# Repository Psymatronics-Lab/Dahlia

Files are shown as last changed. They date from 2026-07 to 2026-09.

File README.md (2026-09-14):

<p align="center">
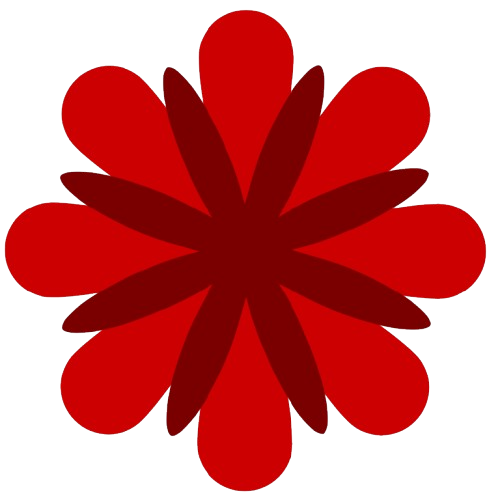
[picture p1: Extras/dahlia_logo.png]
Dahlia Logo
  
</p>

# Dahlia
**Dahlia** is a open-source, 5+1 DOF robotic arm designed for small scale pick and place, educational, and data collection tasks.
<p align="center">
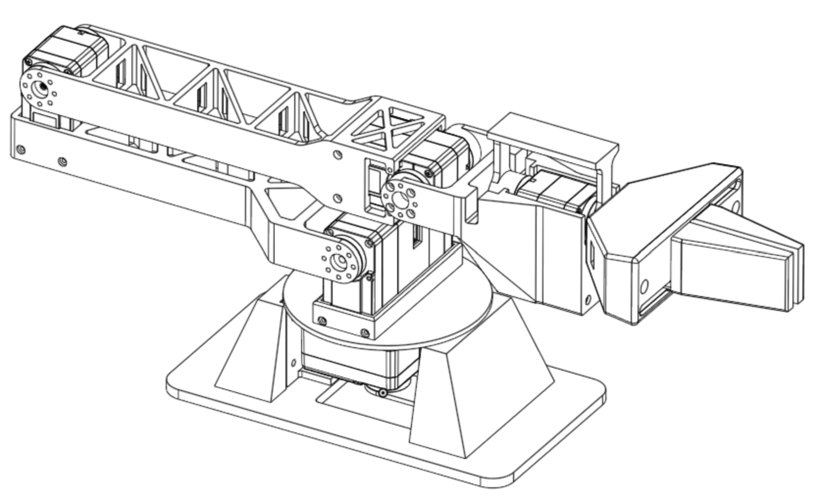
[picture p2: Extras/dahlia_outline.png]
Dahlia Outline
  
</p>

The primary inspiration for the design was the [LeRobot and Huggingface SO-101](https://huggingface.co/docs/lerobot/en/so101) open-source robotic arm, and the [HiWonder NexArm](https://www.hiwonder.com/products/nexarm). The goal of the project was to design an open-source arm with 3D-printable hardware, at a fairly accessible price, while improving upon the specifications of the SO-101 and similar arms in terms of load capacity, reach, and form factor.

This repository contains the hardware, firmware, and software for the Dahlia arm and its SEC controller, organized as follows:
```text
Dahlia/
├── Hardware/
│   ├── dahlia_hardware/          # Arm printed parts (base, arm, end effector), URDF, and sim scripts
│   └── sec_hardware/             # SEC controller printed parts, components, and wiring
├── Firmware/
│   ├── dahlia_firmware/          # Arduino App Lab app for the UNO Q
│   │   ├── sketch/               # MCU servo loop and SPI service
│   │   ├── bricks/spi_service/   # MPU-side HTTP to SPI bridge
│   │   └── python/               # Kinematics and SEC teleoperation control
│   ├── dahlia_services/
│   │   ├── HXServo/              # Arduino library for Hiwonder HX bus servos
│   │   └── controller_service/   # BLE proxy service for the SEC on the UNO Q
│   └── sec_firmware/             # ESP32-S3 firmware for the SEC controller
├── Software/
│   ├── lerobot/                  # LeRobot plugin for the arm and SEC teleoperator
│   └── perception/               # Prototype MicroTag detection pipeline
└── Extras/
    ├── microtag_block/           # Printable MicroTag fiducial blocks
    └── utilities/                # Servo ID hotfix and servo visualization tools
```

## Design, Stack, and BOM
The full CAD design for the Dahlia arm were created using OnShape and a bit of Autodesk Fusion. All editable CAD files are available on the [OnShape Document](https://cad.onshape.com/documents/8e567048457d8f314f3cf9ea/w/dc4364e539049e2561969525/e/322bc6f20473a79fe384e2b4). 

Dahlia is a 5+1 DOF arm, consisting of base rotation joint, co-planar shoulder, elbow, and wrist-pitch joints, and a wrist-roll joint, as well as a gear-driven linear clamp as the end effector. HiWonder bus servos were chosen to be the main actuators for the design due to their relatively low cost for power trade off and similar firmware interface as Feetech STS servos. A Arduino UNO Q is used to directly interface with the BusLinker servo controller to control the arm. A webcam can be mounted on-top of the arm, attached to the wrist-roll bracket, for vision and data collection. Wiring channels and lightening holes are built into the design to reduce material usage and improve wire management.

A full bill of materials needed to construct the arm is listed below. *Note that some manufacturing and connective equipment, such as a 3D printer (BambuLab X2D was used for all prints in construction), hex keys, soldering iron and USB-C cabling are not included.*
| **Component** | **Link** | **Units** | **Price (at time)** | **Total Price** |
| --- | --- | ---: | ---: | ---: |
| Hiwonder HX-30HM | [Hiwonder](https://www.hiwonder.com/products/hx-30hm?variant=42135141253207) | 4 | $19.99 | $79.96 |
| Hiwonder HX-65HM | [Hiwonder](https://www.hiwonder.com/products/hx-65hm?variant=42066913132631) | 1 | $49.99 | $49.99 |
| Hiwonder BusLinker v3 | [Hiwonder](https://www.hiwonder.com/products/buslinker) | 1 | $9.99 | $9.99 |
| Hiwonder LFD-01M | [Hiwonder](https://www.hiwonder.com/products/lfd-01m?variant=39328236896343) | 1 | $6.99 | $6.99 |
| Arduino UNO Q 4GB | [Arduino](https://store-usa.arduino.cc/pages/uno-q) | 1 | $59.99 | $59.99 |
| M3 Heat Set Inserts | [Amazon](https://www.amazon.com/Threaded-Inserts-Plastic-3mm-10mm-Pringting/dp/B0FD88XTV4/) | 1 | $9.99 | $9.99 |
| M3 Screws | [Amazon](https://www.amazon.com/Fgruh-750PCS-Assortment-Washers-Assorted/dp/B0FGV5FCBN/) | 1 | $9.99 | $9.99 |
| M2 Screws | [Amazon](https://www.amazon.com/Fgruh-1260pcs-M2-Assortment-Stainless/dp/B0FG2CC91J/) | 1 | $9.99 | $9.99 |
| Logitech C270 Webcam | [Amazon](https://www.amazon.com/Logitech-Desktop-Widescreen-Calling-Recording/dp/B004FHO5Y6) | 1 | $16.89 | $16.89 |
| 9V Barrel Jack Power Supply | [Amazon](https://www.amazon.com/Interchangeable-Switching-Compatible-Universal-Electronics/dp/B0CPPPKP91/) | 1 | $9.99 | $9.99 |
| | | | **Total Cost:** | **$263.77** |
> [!NOTE]
> A [HiWonder bus servo controller](https://www.hiwonder.com/products/serial-bus-servo-controller) instead of a BusLinker and Arduino UNO Q setup, to directly command the arm from a local computer, may be more cost-efficient and effective for some applications.

## Assembly and Setup
To assemble the arm, acquire the components listed in the BOM, and print the 3D-printable components in the hardware `.step` files for each section of the arm, using any 3D printer (around 0.5kg of PLA filament should be sufficient).

Use the following instructions to construct the arm.
1. Attach all included servo horns to the HiWonder servos, and set each servo to a different ID using the BusLinker board.
2. Use a soldering iron to set the 4 heat-set inserts into the holes in the base plate.
3. Use M2 screws to attach a HX-30HM servo (**base rotation**) to the base servo mount, and attach the base rotation bracket to the servo horns using M2 screws.
4. Attach the base servo mount to the base plate using M3 screws, ensuring the servo wire ports are oriented upward. Attach two wires into the servo ports, and route one wire through the wire divot in the base plate.
5. Attach the rotation plate to the base rotation servo and base rotation bracket using M2 screws.
6. Mount the HX-65HM servo (**shoulder**) into the rotation plate, using its included screws to mount it to the plate, and connect the base rotation servo wire not routed through the divot to the shoulder servo.
7. Mount a HX-30HM servo (**elbow**) into the upper arm using M2 screws, then attach the upper arm to the shoulder servo using M2 screws.
8. Mount a HX-30HM servo (**wrist pitch**) into the lower arm using M2 screws, then attach the lower arm to the elbow servo using M2 screws.
9. Mount the wrist roll bracket on the remaining HX-30HM servo (**wrist roll**) using M2 screws, then mount the wrist roll servo into the wrist using M2 screws.
10. Attach the wrist to the wrist pitch servo, using M2 screws.
11. Mount the end effector housing onto the wrist roll servo and wrist roll bracket using M2 screws.
12. Mount the LFD-01 servo (**end effector**) into the end effector housing using M2 screws, and attach the end effector gear directly to the servo using the servo's horn screw.
13. Slot the linear clamps through the end effector cap and into the housing channels symmetrically on either side of the gear, then attach the cap to the housing using M3 screws.
14. Connect the bus servos together with wiring, threaded through the wiring channels in the upper and lower arms, and connect the end effector servo to the Arduino UNO Q.
15. Connect the other bus wire on the base rotation servo to the BusLinker, and connect the TX/RX channels of the BusLinker to the Arduino UNO Q, ensuring that the bridges on the BusLinker are between Servo and TTL, and not Servo and USB.

All firmware and software needed to run and command the arm is provided in the repository. Refer to the `README.md` and related documentation in the `Software/` and `Firmware/` folders to conduct this setup, which involves creating an AppLab app, setting up services on the Arduino UNO Q, installing the app, and using an external Bluetooth controller to send commands to the UNO Q.

The repository additionally includes a full HXServo library, for control of HiWonder servos, adapted from HiWonder firmware code.
- BusLinker Documentation [https://docs.hiwonder.com/projects/BusLinker/en/latest/index.html](https://docs.hiwonder.com/projects/BusLinker/en/latest/index.html)
- Public Firmware for HX-30HM [https://drive.google.com/drive/folders/1ZyeM3iiXFUqOsPx-hs1AgcEjACiQLcII](https://drive.google.com/drive/folders/1ZyeM3iiXFUqOsPx-hs1AgcEjACiQLcII)

> [!IMPORTANT]
> Due to resourcing constraints in constructing a leader-follower arm setup, Dahlia is originally designed to work with a SEC (Semi-Extensible Controller), for which there is provided firmware and hardware designs in this repository. However, because the Bluetooth Low Energy service is implementation-agnostic and instead uses a standardized packet format, it is possible to use another Bluetooth-compatible controller to control the arm.

## Usage
Once the arm is assembled and the firmware is set up, the arm can be driven directly with the SEC, recorded and replayed through LeRobot, or commanded by any program that reaches the UNO Q over HTTP.

```text
  SEC controller ──BLE──► controller_service (:8000) ──► python/main.py ──► spi_service (:9000) ──SPI──► MCU ──► servos
                                                                                 ▲
                                                           LeRobot, servo_viz, or custom programs over HTTP
```

### Controlling the Arm with the SEC
1. Make sure the `sec-controller` service is running on the UNO Q (see [`controller_service`](Firmware/dahlia_services/controller_service/README.md)).
2. Power the arm and start the Dahlia Firmware app in App Lab. On startup, the MCU drives every joint to its zero pose, so keep the workspace clear.
3. Power the SEC, holding it still with the joystick centered while it calibrates. The arm begins responding once the controller connects.

| **Input** | **Effect** |
| --- | --- |
| Joystick X | Moves the end effector straight up and down |
| Joystick Y | Moves the end effector toward or away from the base |
| Joystick button (**hold**)  | Gyroscopic following: controller roll turns the base, controller pitch tilts the end effector |
| Rotary encoder (**turn**) | Rolls the end effector |
| Encoder button (**click**)  | Toggles the clamp fully open or fully closed |
| **Both buttons** | Returns the arm to its startup pose |

The LED matrix on the SEC shows the joystick, button, and IMU readings for quick diagnostics. Motion speeds, joystick thresholds, and safety limits can be tuned in [`control.py`](Firmware/dahlia_firmware/python/control/control.py), and are explained in the [control README](Firmware/dahlia_firmware/python/README.md).

### Using LeRobot
The [`lerobot-dahlia`](Software/lerobot/README.md) plugin runs on a separate PC and provides the arm as the `dahlia` robot and the SEC as the `dahlia_sec` teleoperator, both reached at the UNO Q's SPI service URL.

```bash
pip install -e "Software/lerobot[camera]"

# check the connection to the arm without LeRobot
python -m lerobot_dahlia.dahlia_bus http://dahlia.local:9000

# record episodes while driving the arm with the SEC
lerobot-record \
  --robot.type=dahlia --robot.port=http://dahlia.local:9000 \
  --teleop.type=dahlia_sec --teleop.port=http://dahlia.local:9000 \
  --robot.discover_packages_path=lerobot_dahlia \
  --dataset.repo_id=you/dahlia_pick --dataset.num_episodes=10 \
  --dataset.single_task="Pick up the block"
```

- **Teleoperating and recording.** The SEC control loop stays on the UNO Q, and LeRobot only reads what the arm is being commanded. The robot defaults to `read_only=true` for these tasks, so LeRobot never fights the SEC.
- **Replaying and running policies.** Pass `--robot.read_only=false` so LeRobot commands the arm, and disconnect the SEC first so only one program is driving it.
- **Cameras.** The wrist camera is recorded as `observation.images.wrist`. Find its device index with `lerobot-find-cameras opencv` and set it in `dahlia_robot.py` or with `--robot.cameras`.

### Developing with Dahlia
The SPI service on the UNO Q exposes the arm over HTTP on port `9000`, so new software can be written in any language on the board or on another machine on the network.

| **Endpoint** | **Use** |
| --- | --- |
| `GET /config` | Joint names, tick limits, and angle limits |
| `GET /feedback` | Measured joint angles in radians |
| `POST /targets` | Command joint angles in radians |
| `GET /motors` | Full raw motor state, including load, voltage, and temperature |
| `POST /motors` | Command raw servo ticks, or `{"hold": true}` to hold the current pose |
| `GET /command` | What the arm is currently being commanded, and in which mode |
| `GET /health` | SPI service status |

> [!WARNING]
> Only one program should command the arm at a time. `POST /targets` and `POST /motors` overwrite each other, so a second writer will cause the arm to jerk between commands. All commands are still clamped to the joint limits set in the MCU firmware.

A few starting points in the repository:
- **New control schemes.** [`kinematics.py`](Firmware/dahlia_firmware/python/control/kinematics.py) provides closed-form forward and inverse kinematics, and [`main.py`](Firmware/dahlia_firmware/python/main.py) is a short example of reading a controller and posting joint targets.
- **Other controllers.** Any BLE device that sends the SEC packet format in [`ble.h`](Firmware/sec_firmware/src/ble/ble.h) can replace the SEC, and the SEC's breadboard and firmware can be extended with new inputs.
- **Monitoring.** [`servo_viz`](Extras/utilities/servo_viz/README.md) plots commanded against measured joint angles live from a workstation, using only read-only endpoints.
- **Simulation.** The URDF in [`Hardware/dahlia_hardware`](Hardware/dahlia_hardware/README.md) can be converted to a simulation-ready model for simulation and RL training.
- **Perception.** [`Software/perception`](Software/perception/) contains an OpenCV detection pipeline for the [MicroTag blocks](Extras/microtag_block/README.md).

## Notes and Acknowledgements
Dahlia was designed in part for the "Invent the Future with Arduino UNO Q and App Lab" challenge, hosted by [Hackster.io](https://www.hackster.io/contests/invent-the-future-with-arduino-uno-q-and-app-lab). Thank you to Hackster.io for providing the Arduino UNO Q hardware that was used to design and construct the project.

> [!NOTE]
> As the first project for the Psymatronics Lab, there is definitely more extension to be done on Dahlia and much was learned from designing and troubleshooting the arm. I hope to continue to build out the software stack of Dahlia, and begin designing **Dahlia II**, which will be an enhanced arm, designed for low-cost research and data-collection applications.

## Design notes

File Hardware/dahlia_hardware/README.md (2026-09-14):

# Dahlia Arm Hardware
All the `.step` files needed to print a Dahlia arm are included in this section of the repository, alongside `.urdf` files and meshes for simulation and RL training.

The full URDF contains a few unnecessary joints and sections that may hamper simulation performance, and thus a simulation-ready version with merged meshes and proper joints can be generated using the following code. Only `numpy` needs to be installed for this.
```bash
python urdf_merge_subassemblies.py path/to/robot_full/urdf/robot_full.urdf -o path/to/robot_sim
```

## Printed Parts
| **Folder** | **Files** |
| --- | --- |
| `base/` | `base_body`, `base_servo_mount`, `base_rotation_plate`, `base_rotation_bracket` |
| `arm/` | `arm_upper_arm`, `arm_lower_arm`, `arm_wrist`, `arm_wrist_rotation` |
| `end_effector/` | `ef_body`, `ef_gear`, `ef_clamp` (print two, one per side), `ef_front_cap` |

## Components
| **Component** | **Units** | **Purpose** |
| --- | ---: | --- |
| Hiwonder HX-65HM | 1 | Shoulder joint |
| Hiwonder HX-30HM | 4 | Base rotation, elbow, wrist pitch, and wrist roll joints |
| Hiwonder LFD-01M | 1 | PWM servo driving the end effector gear and clamp |
| Hiwonder BusLinker v3 | 1 | Bridges the UNO Q's UART to the servos' single-wire serial bus |
| Arduino UNO Q | 1 | Runs the servo loop (MCU) and the control and BLE services (MPU) |
| 9V power supply | 1 | Servo power, through the BusLinker's DC input |
| Logitech C270 webcam  | 1 | Optional, mounted to the wrist-roll bracket for vision |

See the BOM in the [main README](../../README.md) for purchase links and fasteners.

## Wiring
```text
  9V supply ──► BusLinker v3 DC input
                     │
  UNO Q Serial1 ◄──► BusLinker v3 ──bus──► HX servos (IDs 1-5, daisy-chained)
  UNO Q D3 (PWM) ─────────────────────────► LFD-01M clamp servo
```

### Bus Servos
| **UNO Q** | **BusLinker v3** | **Notes** |
| --- | --- | --- |
| `Serial1` TX  | RX | TX and RX are crossed |
| `Serial1` RX  | TX | TX and RX are crossed |
| GND | GND | A shared ground is required |

The servos are daisy-chained from the BusLinker's servo bus and powered from the BusLinker's DC input, never from the UNO Q's 5V pin. The bus runs at 1,000,000 baud, and each servo must be assigned the ID the firmware expects, from [`servo_interface.h`](../../Firmware/dahlia_firmware/sketch/src/low_level/servo_interface.h):

| **Joint** | **Servo** | **ID** |
| --- | --- | -----: |
| Base rotation| HX-30HM | 1 |
| Shoulder | HX-65HM | 2 |
| Elbow | HX-30HM | 3 |
| Wrist pitch  | HX-30HM | 4 |
| Wrist roll | HX-30HM | 5 |

Set IDs with one servo connected at a time, since servos sharing an ID on the same bus will corrupt it. [`Extras/utilities/id_hotfix.ino`](../../Extras/utilities/id_hotfix.ino) can be used to change a servo's ID.

### Clamp Servo
The LFD-01M signal wire connects to UNO Q pin D3 (`SIGPIN` in `servo_interface.h`), which is driven with a 50 Hz PWM signal. Its ground must be shared with the UNO Q.

### UNO Q and Webcam
The UNO Q is powered over USB-C. The webcam connects over USB to the device used for vision and data collection (not necessarily the UNO Q). Route servo cables through the wiring channels built into the printed parts.

For further wiring and bus troubleshooting details, see the [HXServo README](../../Firmware/dahlia_services/HXServo/README.md).

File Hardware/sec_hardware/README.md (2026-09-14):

# Semi-Extensible Controller Hardware
The 3D-printable parts for the SEC (Semi-Extensible Controller) are in this section of the repository. The SEC is a handheld Bluetooth Low Energy controller used to teleoperate the Dahlia arm. Firmware and setup instructions are in [`Firmware/sec_firmware`](../../Firmware/sec_firmware/).

## Printed Parts
| **File** | **Description** |
| --- | --- |
| `sec_body.step` | Main controller body |
| `sec_encoder_knob.step`| Knob for the rotary encoder shaft |

## Components
| **Component** | **Model** | **Purpose** |
| --- | --- | --- |
| ESP32-S3 development board | ESP32-S3 | Reads the inputs and broadcasts them over BLE |
| 2-axis joystick | KY-023 | Reach and height jogging, gyro-follow button |
| Rotary encoder | KY-040 | Wrist roll, clamp open/close button |
| 6-axis IMU | MPU6050 | Controller roll and pitch for gyroscopic following  |
| 8x8 LED matrix | MAX7219 | Minimal diagnostic and telemetry display |
| Breadboard | — | Integrated into the controller for extensibility |

## Wiring
Pin assignments are defined in [`Firmware/sec_firmware/config.h`](../../Firmware/sec_firmware/config.h). All numbers below are ESP32-S3 GPIO numbers, and every component must share a common ground with the ESP32-S3.

### Joystick (KY-023)
| **KY-023 Pin** | **ESP32-S3** |
| --- | --- |
| VRx | GPIO 4 |
| VRy | GPIO 5 |
| SW | GPIO 6 |
| +5V | 3.3V |
| GND | GND |

The X and Y outputs are read by the ESP32's ADC, so power the joystick from 3.3V to keep the analog outputs within the ADC's input range. The switch uses the ESP32's internal pull-up, so no external resistor is needed.

### Rotary Encoder (KY-040)
| **KY-040 Pin** | **ESP32-S3** |
| --- | --- |
| CLK (A) | GPIO 9 |
| DT (B) | GPIO 10 |
| SW | GPIO 11 |
| + | 3.3V |
| GND | GND |

All three encoder inputs use the ESP32's internal pull-ups.

### IMU (MPU6050, I2C)
| **MPU6050 Pin** | **ESP32-S3** |
| --- | --- |
| SDA | GPIO 13 |
| SCL | GPIO 14 |
| VCC | 3.3V |
| GND | GND |

The firmware expects the IMU at I2C address `0x68`, so leave `AD0` unconnected or tied low.

### LED Matrix (MAX7219, SPI)
| **MAX7219 Pin** | **ESP32-S3** |
| --- | --- |
| DIN | GPIO 40 |
| CS | GPIO 41 |
| CLK | GPIO 42 |
| VCC | 5V |
| GND | GND |

### Power
The ESP32-S3 is powered through its USB port, and supplies the 3.3V and 5V rails to the components. Once powered, the controller calibrates the joystick center and IMU gyroscope, so keep the joystick centered and the controller still for a moment after plugging it in.

> [!TIP]
> If a joystick axis, the encoder direction, or an IMU axis responds in the opposite direction from what is expected after assembly, flip it in firmware using the `FLIP_*` constants in `joystick.h`, `rotencoder.h`, and `imu.h` rather than rewiring.

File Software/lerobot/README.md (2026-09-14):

# lerobot-dahlia
A LeRobot plugin providing the Dahlia arm as a robot and the SEC controller as a teleoperator. Runs on a PC; the arm is reached over HTTP.

```text
  SEC controller
     |  BLE
  controller_service           (UNO Q host, systemd)
     |  HTTP :8000
  python/main.py               (UNO Q, joystick -> IK -> joint targets)
     |  POST /targets                        |  GET /command
  bricks/spi_service           (UNO Q, :9000)  ---------------+
     |  SPI, 100 Hz                                           |
  sketch/                      (MCU, 200 Hz servo loop)       |  HTTP
     |  UART                        |  PWM                    |
  HX-HM bus servos (5 joints)   clamp (gripper)               |
                                                     LeRobot on this PC
                                                     robot: dahlia
                                                     teleop: dahlia_sec
```

The SEC control loop stays on the board, where it needs to be for latency. LeRobot reads its output rather than re-deriving it.

## Install
```bash
pip install -e Software/lerobot          # add [camera] for the OpenCV backend
```

## Registering with LeRobot's CLI
`--robot.type=dahlia` resolves through a registry that the `@register_subclass` decorators fill at import time, so something has to import `lerobot_dahlia` before the CLI parses arguments. LeRobot's plugin discovery flag does that:

```bash
uv run lerobot-teleoperate --robot.type=dahlia --robot.port=http://dahlia.local:9000 --teleop.type=dahlia_sec --teleop.port=http://dahlia.local:9000 --robot.discover_packages_path=lerobot_dahlia
```

Confirm your version has it with `lerobot-record --help | grep discover`. If it does not, importing the package before the CLI runs has the same effect — the registration is a plain import side effect, nothing LeRobot-version specific.

## Recording
```bash
lerobot-record \
  --robot.type=dahlia --robot.port=http://dahlia.local:9000 \
  --teleop.type=dahlia_sec --teleop.port=http://dahlia.local:9000 \
  --robot.discover_packages_path=lerobot_dahlia \
  --dataset.repo_id=you/dahlia_pick --dataset.num_episodes=10 \
  --dataset.single_task="Pick up the block"
```

## Modules
| Module | Contents |
|---|---|
| `dahlia_bus.py` | `HXServoMotorsBus`, a `MotorsBus` speaking raw servo ticks over HTTP |
| `dahlia_robot.py` | `DahliaRobot` / `DahliaRobotConfig`, six joints plus cameras |
| `dahlia_teleop.py` | `DahliaSECTeleop` / `DahliaSECTeleopConfig` |
| `dahlia_calibration.py` | the fixed calibration, and radians to normalised conversion |

## Calibration
Dahlia needs no interactive calibration pass. Its travel is fixed in firmware: `servo_interface.h` holds a `joint_configs` table the MCU clamps every command against, so those stops **are** the calibration. `dahlia_calibration()` derives `MotorCalibration` straight from that table, and `DahliaRobot` applies it on construction, so the arm is usable the moment it connects.

`drive_mode` is set to 1 on every joint whose ticks count *down* as the angle goes up, which is all of them except the base. That is what makes **-100 mean minimum angle and +100 mean maximum angle on every joint**, instead of the normalised direction flipping around depending on how each servo happens to be mounted. `dahlia_teleop` depends on that: it means one expression converts an angle to a normalised action for every joint.

## Why the teleoperator only reads
The SEC is not a leader arm, but LeRobot never asks whether it is. A `Teleoperator` returns an action each tick and has no opinion on where it came from — `SO101Leader.get_action()` reads joint positions off a serial bus, this reads them off `GET /command`.

Re-deriving the action here instead, from the raw BLE samples, would look simpler and be wrong. The mapping in `python/control/control.py` is stateful and rate dependent: the pose integrates a thresholded joystick, the gyro reference latches on the sample where the button is first seen held, and the clamp toggles on a *release edge*. A second copy polling at LeRobot's rate drifts from the copy actually driving the arm. The clamp is the sharp edge — a click shorter than one poll interval is invisible to the slower sampler, and because it is a toggle, one missed click inverts the gripper for the rest of the episode. The arm grasps, the dataset says it did not, and every frame after that is mislabelled.

Reading the *command* rather than the measured pose matters too: the measurement lags the command and settles onto it, so recording it as the action would teach a policy to output the state it is already in.

When nothing is driving the arm in radians, `get_action()` holds its previous action instead of jumping.

## Who owns the arm

The SPI service keeps **one** command struct with **one** mode field, and its two POST routes overwrite each other's: `/targets` sets `MODE_ANGLE` and commands radians, `/motors` sets `MODE_RAW` and commands ticks. Whichever posted last wins, and the MCU re-reads the mode every servo cycle.

LeRobot's loops call `robot.send_action()` every tick regardless of what else is driving. With `python/main.py` running that makes two writers, the mode flips at the rate the two of them post, and the arm jerks around the commanded pose as the MCU alternates between the two command spaces. The teleoperator's own `MODE_ANGLE` guard then trips on the robot's write from the previous tick and starts holding stale actions, which makes it worse.

Ownership cannot be detected, so it is declared. `python/main.py` is the App Lab application and runs continuously; there is also no liveness signal to read even if it did not, because the service resends the command struct at 100 Hz whether or not anything is updating it. The MCU therefore stays `fresh` as long as the brick runs, and the mode keeps whatever was last posted — a single POST to `/targets` leaves the mode reading `MODE_ANGLE` indefinitely, even if the sender has stopped.

So `DahliaRobotConfig.read_only` decides it, defaulting to observing:

| Task | `read_only` | Behaviour |
|---|---|---|
| `lerobot-teleoperate`, `lerobot-record` | `true` (default) | Returns the action for the dataset, sends nothing. The SEC drives. |
| `lerobot-replay`, policy evaluation | `--robot.read_only=false` | Commands the arm. |

The default is the safe direction: forgetting the flag on a replay leaves the arm still and logs why, while forgetting it the other way corrupts a recording and fights a live teleoperator.

Driving also needs the SEC path to actually stand down, which does not require stopping the App Lab application — `main.py` only posts `/targets` while the controller is connected, so disconnecting the SEC is enough. If you drive while the command space is still set to radians, `send_action()` warns once rather than fighting quietly.

## Cameras

The views recorded into every episode:

| Key | Mounting | Observation feature | |
|---|---|---|---|
| `wrist` | on the end effector | `observation.images.wrist` | active, device index 1 |
| `overhead` | fixed above the workspace | `observation.images.overhead` | commented out in `dahlia_cameras()` |

Only the wrist view is live at the moment. Restoring the overhead one is uncommenting its parameter and its dict entry in `dahlia_cameras()`, but note that adding a camera changes `observation_features`, so episodes recorded with one view and with two are not the same dataset.

`wrist` is LeRobot's name for an end effector camera, so datasets and policy configs that expect that key line up without remapping. It sits alongside the `wrist_pitch` and `wrist_roll` *joints*, which are a different thing — joints always carry a `.pos` suffix, cameras never do.

Device indices are per machine, because OpenCV numbers cameras by enumeration order. `lerobot-find-cameras opencv` lists what is attached; set `WRIST_CAMERA_INDEX` and `OVERHEAD_CAMERA_INDEX` in `dahlia_robot.py`, or override the pair on the command line:

```bash
--robot.cameras='{ wrist: {type: opencv, index_or_path: 1, width: 1280, height: 720, fps: 15}, overhead: {type: opencv, index_or_path: 2, width: 1280, height: 720, fps: 15}}'
```

Both are MJPG at 1280x720/15 through the DirectShow backend. MJPG is not cosmetic: two uncompressed streams of this size do not fit through one USB controller, and the second camera opens and then starves. If a camera refuses the format, set `CAMERA_FOURCC = None` and drop the resolution instead, and put the two cameras on separate USB controllers rather than a shared hub.

There are no intrinsics or extrinsics here. LeRobot treats a camera as an image source — `OpenCVCameraConfig` carries only index, size, fps, colour and rotation — and its policies learn from pixels, so nothing in the record or replay path needs a calibrated camera. Mapping an overhead detection into arm coordinates, or hand-eye calibrating the wrist camera against the URDF, would need both, but that belongs with `Software/perception/` rather than here.

## Bring-up
Check the bus on its own, without LeRobot:
```bash
python -m lerobot_dahlia.dahlia_bus http://dahlia.local:9000
```
Prints the service config, per-joint load/voltage/temperature, and raw plus normalised positions.

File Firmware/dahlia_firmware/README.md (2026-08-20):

# Dahlia Arm Firmware
Firmware for the Dahlia Arm, running on the Arduino UNO Q MPU and MCU as an App Lab app.

```text
  host (BLE teleop on the MPU, or lerobot on another machine)
     |  HTTP :9000
  bricks/spi_service        MPU, Debian container
     |  SPI, 100 Hz, fixed 89-byte frame
  sketch/                   MCU, Zephyr -- owns the 200 Hz servo loop
     |  UART, Hiwonder 0xFF protocol       |  PWM
  HX-HM bus servos (5 joints)              clamp servo (gripper)
```

The MCU owns the servo loops, mechanical joint limits in raw servo ticks and rotation angles,
and stale command filter. Anything above provides servo commands through the SPI service.

## Command Spaces
A single SPI frame carriers two command spaces, using a mode field to indicate which space
is in effect. A single host should only produce a frame consistent with a single command space
unless dynamic switching is implemented.

| Mode | Units | Endpoint | Used by |
|---|---|---|---|
| `MODE_ANGLE` | radians | `POST /targets` | BLE teleoperation (`python/main.py`) and similar |
| `MODE_RAW` | servo ticks | `POST /motors` | anything owning its own calibration, e.g. `Software/lerobot` |
| `MODE_HOLD` | — | `POST /motors {"hold": true}` | hold the present pose |

Raw commands are still clamped to joint limits, both on software and flashed servo firmware. Hosts
that conduct their own calibration cannot drive joints beyond these stops.

## Safety Behaviors
- **Command Authority.** A command older than 500ms stops being authoritative and the arm holds its measured pose with torque rather than continuing toward a commanded target point.
- **Torque Authority.** Torque setting commands are only authoritative when the `TORQUE_APPLY`  bit is set by a controller.
- **No-Torque Tracking.** When torque is off, commands continuously update with the measured position, so re-enabling torque prevents jerking back to old targets. This enables safe hand-teaching and range-of-motion recording.

## HTTP API
- `GET /config`, returns joint names, tick limits, angle limits, encoder resolution.
- `GET /motors`, returns full motor state, including raw positions and velocities, load, voltage, temperature, per-joint torque and comm-error flags, gripper echo, MCU loop counter.
- `POST /motors`, input partial update of servo targets, with every field as optional and unnamed fields keeping their previous value; returns with the same body as `GET /motors`.

```json
{"positions": [0,0,2250,0,1750], "velocities": [3400,...],
 "acceleration": [254,...], "torque": [true,...], "gripper": 128}
```

- `GET /feedback`, `POST /targets`, radian based API, similar to the `/motors` API.
- `GET /command`, returns what is currently being *commanded* in both spaces, plus the active mode. This is the readback a recorder needs: the measured pose lags the command and settles onto it, so recording the measurement as the action would teach a policy to output the state it is already in.
- `GET /health`, returns whether the SPI thread is alive, how old the last frame is, and the consecutive error count.

## Protocol Format
`CommandPacket` is 70 bytes, `FeedbackPacket` 89, and every transfer clocks 89 either way. The sketch `static_assert`s both against a per-joint formula, so changing a field without mirroring it in `bricks/spi_service/spi_service.py` is a build error.

## Interfacing with LeRobot
`brick_compose.yaml` publishes port 9000 on the board, so an off-board host can reach the raw API. LeRobot runs on a PC through the `lerobot-dahlia` plugin in `Software/lerobot`, whose `--robot.port` is this service's URL.

The SEC control loop stays on the board for latency, and LeRobot reads its output through `GET /command` rather than re-deriving it from the raw controller samples. `Software/lerobot/README.md` explains why re-deriving it would silently corrupt recorded episodes.

Check the arm without LeRobot in the way:
```bash
python -m lerobot_dahlia.dahlia_bus http://dahlia.local:9000
```

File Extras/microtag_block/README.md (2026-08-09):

# MicroTag Blocks
Microtag blocks are a custom fiducial component designed to test CV pipelines and be low cost to print and assemble, while still acting as workable fiducials for small scale testing and localization.

Each block is a 35mm cube, printed from white PLA plastic (or an equivalent material), with a 25mm frame of black PLA plastic embedded into all six faces, containing a 15mm square of 5mm pieces in a 3 by 3 format. Each 3 by 3 contains 5 white adn 4 black pieces, and each fiducial pattern is orientable and uniquely identifiable by the 3 by 3 pattern. Only a single corner of the larger 3 by 3 square contains a white or black cube (while the other 3 corners contain opposing colors), and this corner determines the pattern orientation. Each face of the MicroTag block contains a different 3 by 3 pattern. 

From these restrictions, a few unique patterns are possible. We select 6 to be our canonical side patterns, with 3 having white corner orienations and 3 having black corner orientations. These are listed as follows, with `O` being a white block and `X` being a black block.
```text
Pattern 1:
O O X
O X O
X O X

Pattern 2:
X O O
O X X
O X O

Pattern 3:
O X X
O O O
X O X

Pattern 4:
X O O
X O X
O X O

Pattern 5:
O O X
O O X
X O X

Pattern 6:
X X O
O X O
O X O
```

MicroTag Blocks can thus be used as fiducials as well as pick-and-place, trackable objects by camera-enabled robotic arms. They can be easily 3D printed at relatively low cost, stand on their own in any orthogonal orientation without needing additional supports, be localized and posed when viewed from any camer orientation, and be stacked and layered.

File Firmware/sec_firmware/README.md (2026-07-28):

# Semi-Extensible Controller
The semi-extensible controller is a custom, programmable controller designed to control the Dahlia arm. It's current configuration includes a 2-axis joystick, rotary encoder, and 6-axis IMU wired to an ESP32-S3 board, with a LED matrix for minimal diagnostic and telemetry display, and an integrated breadboard for extensibility.

## Setup
After assembling the controller, flash the ESP32 using Arduino IDE, with the `NimBLE-Arduino` library installed, to install the `sec_firmware`. Then, when the controller is connected to power, it will automatically begin broadcasting telemetry packets on Bluetooth Low Energy.
- Use LightBlue to check if BLE is actually functioning correctly, and that it is possible to subscribe to notifications.
- Ensure that receiving device (i.e., the Dahlia Arm) has a Bluetooth client server that searches for a UUID matching the SEC broadcast UUID.

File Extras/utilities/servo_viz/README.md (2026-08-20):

# Arm monitor

A workstation-side plot of what the arm is told to do against what it actually does,
built to find where the approach angle is being lost when the end effector changes
height.

It needs no firmware change and cannot affect the arm. Every request is a `GET`
against one of three endpoints that already exist:

| service | port | endpoint | what it gives |
| --- | --- | --- | --- |
| `ble_service.py` | 8000 | `/controller` | the live SEC sample |
| `spi_service.py` | 9000 | `/command` | the joint angles `main.py` is asking for |
| `spi_service.py` | 9000 | `/feedback` | the joint angles the servos report |

Both services already bind `0.0.0.0`, and the SPI service is published on the board by
`brick_compose.yaml`, so both are reachable from the LAN as they stand. The set is
declared in `READ_ONLY` and `Poller.get` refuses anything outside it, so the `POST`
routes that command the arm are unreachable from this tool by construction.

## Running

```
python Extras/utilities/servo_viz/servo_viz.py --board 192.168.1.50
```

`--board` takes the board's hostname or IP and defaults to `dahlia.local`. Add
`--log climb.csv` to record every sample alongside the plot. Press `r` in the window
to reseed the independent controller.

## The three traces

Each joint carries three lines, and the pairs answer different questions.

**commanded against measured** is servo tracking. Gravity droop and per joint lag live
here. This is the pair to watch while driving the arm up and down, since the approach
pitch is the sum of shoulder, elbow, and wrist pitch, so all three joints' errors land
on the end effector angle undiluted.

**independent against commanded** is the control path. The independent trace is this
process running the real `control.ArmController` against the same SEC sample the arm
just received, so if the two diverge, the arm is not being sent what the control code
says it should be. If they sit on top of each other, teleoperation and IK are fine and
the fault is downstream.

The top panel plots the approach pitch itself, which is the quantity the arm is
visibly failing to hold.

## Reading it honestly

The independent controller is seeded from the commanded vector, not the measured one,
so it starts level with the commanded trace and any gap between them is genuinely the
control path rather than inherited droop. It is still an open loop mirror: it began at
a different time than the arm's own controller and integrates encoder counts and gyro
references from that moment, so slow divergence over minutes is expected rather than a
finding. Press `r` to reseed before a measurement that matters.

`/command` only carries radians in `MODE_ANGLE`. Under the LeRobot path the arm runs in
`MODE_RAW` and the field is stale, so the commanded trace is blanked and the banner
shows the mode.

Polling is three small JSON reads per tick, 60 requests per second at the default rate.
That is modest but not free, and it defaults to 20 Hz because `control.PERIOD` assumes
it: the independent controller advances its reach and height by a fixed amount per
poll, so at another rate it still solves correctly but travels at the wrong speed in
wall clock time. `--hz` warns when you change it.

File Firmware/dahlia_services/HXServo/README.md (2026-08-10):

# HXServo — Arduino driver for Hiwonder magnetic-encoder bus servos

An Arduino library for Hiwonder's **HX "HM" magnetic-encoder intelligent serial bus
servos** — `HX-10HM`, `HX-30HM`, **`HX-65HM`**, and the rest of the family. Every
servo in this family uses the same wire protocol and register map, so one driver
class controls all of them; only the mechanical/torque specs differ between models.

This is a port of Hiwonder's original ESP32-only `HX_30HM` reference. It has been
renamed to reflect the whole family, made portable to standard Arduino cores
(AVR / STM32 / etc.), and had its comments rewritten in English.

> **Protocol note.** These servos speak the `0xFF 0xFF`-header *Hiwonder
> Magnetic-Encoder Bus Servo* protocol (a Dynamixel/Feetech-style register
> protocol). This is **not** the `0x55`-header LewanSoul/LX controller-board
> protocol used by the older `LobotServoController` library — that library
> targets a different product line (the LSC controller + LX servos) and cannot
> talk to an HX servo.

---

## Contents
1. [What talks to what](#what-talks-to-what)
2. [Installation](#installation)
3. [Wiring](#wiring)
4. [Quick start](#quick-start)
5. [Bus-servo background you should know](#bus-servo-background-you-should-know)
6. [API reference](#api-reference)
7. [Reading the `ServoStatus_t` result](#reading-the-servostatus_t-result)
8. [Common recipes](#common-recipes)
9. [Troubleshooting](#troubleshooting)
10. [Changes from the original](#changes-from-the-original)

---

## What talks to what

```
  Arduino UNO Q  ──UART(TX/RX/GND)──►  BusLinker V3.0  ──single-wire bus──►  HX-65HM
   (bus master,                        (transparent TTL      (and any other
    runs HXServo)                       <-> bus adapter)       HX-HM servos, daisy-chained)
```

- Your **Arduino is the bus master.** It builds and sends the raw servo protocol.
- The **BusLinker V3.0 is a transparent adapter.** It does not interpret commands;
  it just bridges your full-duplex UART to the servos' half-duplex single-wire bus
  (and provides servo power from its own DC input). So you write full-duplex TX/RX
  code and the adapter handles bus turnaround.
- The **servos** are addressable nodes on a shared bus, each with a unique ID.

---

## Installation

`HXServo` is a plain source library (`.h`/`.cpp`), so it installs anywhere the
Arduino build can find it. The procedure differs between the classic IDE and
**Arduino App Lab** — the latter is what you use on the UNO Q.

The folder already has the layout both toolchains expect:

```
HXServo/
├── HXServo.h
├── HXServo.cpp
├── HXServo_Registers.h      control-table addresses & protocol constants
├── library.properties
├── keywords.txt
├── README.md
└── examples/
    ├── BasicControl/BasicControl.ino
    ├── SyncMotion/SyncMotion.ino
    └── Telemetry/Telemetry.ino
```

### Arduino IDE (classic)

1. Copy the whole `HXServo/` folder into your Arduino `libraries/` directory:
   - Windows: `Documents\Arduino\libraries\HXServo\`
2. Restart the Arduino IDE.
3. `#include <HXServo.h>`.

### Arduino App Lab (Arduino UNO Q)

App Lab differs from the classic IDE in one fundamental way: **your app — the
sketch, its bricks, and its Arduino libraries — is built and stored on the UNO Q
itself, not on your PC.** Your computer's `Documents/Arduino/libraries` folder is
therefore irrelevant here; the library files must be placed on the board's Linux
filesystem, where the on-device toolchain looks for them. App Lab currently has no
"Add .ZIP Library" button, so this is a manual copy.

> App Lab's custom-library workflow is still evolving and the steps below are the
> community-established method rather than an official one-click flow — check the
> forum thread linked at the end of this section for the current state.

1. **Copy the `HXServo/` folder onto the board.** The UNO Q runs Debian Linux, so
   use whichever transfer method you prefer:
   - **SFTP** (e.g. WinSCP) into the board — the community's recommended method,
   - the board's own file manager or a terminal in the App Lab desktop, or
   - `scp` / `adb push` from your PC.

   App Lab apps themselves live under `/home/arduino/arduino_apps/`.

2. **Put the library in a persistent folder you control**, for example:

   ```
   /home/arduino/Arduino/libraries/HXServo/
   ```

   (create the folders if they don't exist). Keeping your source here means a
   toolchain update can't wipe it.

3. **Make the build see it.** App Lab compiles UNO Q sketches with a
   **Zephyr-based** Arduino core, which does *not* auto-scan local library folders
   the way the classic IDE does. In a terminal on the board, find the installed
   core version and symlink the library into its `libraries` path:

   ```bash
   # 1. find the installed Zephyr core version (e.g. 0.1.0)
   ls ~/.arduino15/packages/arduino/hardware/zephyr/

   # 2. symlink the library into that core's libraries folder
   #    (replace <version> with what step 1 printed; mkdir it if missing)
   ln -s /home/arduino/Arduino/libraries/HXServo \
         ~/.arduino15/packages/arduino/hardware/zephyr/<version>/libraries/HXServo
   ```

   Use a **symlink**, not a plain copy into that path: your real files stay in
   your own folder, so a core update won't delete them. (Copying the files
   directly into the core path also works, but they are lost on the next update.)
   As an alternative, you can reference the library from your app's `sketch.yaml`.

4. **Rebuild and run the app** in App Lab, then `#include <HXServo.h>` in your
   sketch.

> **MCU core note.** Because App Lab uses the Zephyr core rather than the classic
> STM32duino core, some libraries need porting — but `HXServo` only uses the
> standard Arduino serial API (`begin(baud, SERIAL_8N1)`, `available`, `read`,
> `write`, `millis`), which the Zephyr core implements, so no code changes are
> needed. If a serial name like `Serial1` doesn't map to the header pins you
> wired, check App Lab's UNO Q pin/serial documentation and adjust `SERVO_SERIAL`
> in the sketch.
>
> Reference: [How to Manually Install a Custom Library — Arduino App Lab
> forum](https://forum.arduino.cc/t/how-to-manually-install-a-custom-library/1415413).

---

## Wiring

| Arduino (UNO Q) | BusLinker V3.0 | Notes |
|---|---|---|
| `Serial1` **TX** | **RX** | TX→RX (crossed) |
| `Serial1` **RX** | **TX** | RX→TX (crossed) |
| **GND** | **GND** | **Mandatory** — a shared ground reference |
| — | **Servo V+ / DC in** | Power the servos from the BusLinker's DC input, sized for the model (e.g. HX-65HM wants a stiff supply) |

Rules of thumb:

- **Cross TX and RX.** The master's transmit goes to the adapter's receive.
- **Common ground is not optional.** Signals are referenced to GND; without a
  shared ground the UART reads garbage or nothing.
- **Do not power a large servo from the Arduino's 5 V pin.** An HX-65HM can pull
  amps under load. Use the BusLinker's dedicated servo power input.
- **Match the baud everywhere.** Servo, BusLinker, and `HXServo(...)` must agree.
  HX-HM servos ship at **1,000,000 bps**. The STM32 on the UNO Q handles 1 Mbps
  fine; if you see corruption, drop all three to 115200 to isolate.

> Picking the right UART: `SERVO_SERIAL` in the sketch must be the hardware serial
> port physically wired to the BusLinker. Use the USB `Serial` only for the debug
> monitor, not for the servo bus.

---

## Quick start

```cpp
#include <HXServo.h>

HXServo servo(Serial1, 1000000);   // bind to the UART wired to the BusLinker

void setup() {
  Serial.begin(115200);            // USB monitor (debug only)
  servo.begin();                   // open the servo bus

  ServoStatus_t st = servo.ping(1);
  if (!st.error_bits.bit_rx) {
    Serial.print("Servo online, ID = ");
    Serial.println(st.id);
  }
  servo.enable_torque(1);          // required before it will move/hold
}

void loop() {
  servo.write_pos_ex(1, /*acc=*/50, /*speed=*/1000, /*pos=*/ 2048);
  delay(1000);
  servo.write_pos_ex(1, /*acc=*/50, /*speed=*/1000, /*pos=*/-2048);
  delay(1000);
}
```

**First-bring-up tip:** open `HXServo.h` and set `#define HX_DEBUG 1`. Every frame
sent and received is then printed (in hex) to the USB `Serial`, which makes
wiring/baud/ID problems obvious. Set it back to `0` for normal operation.

---

## Bus-servo background you should know

If you have only used hobby PWM servos before, serial bus servos work differently.
The essentials:

- **Bus, not one-wire-per-servo.** Every servo shares one data bus and is
  addressed by a unique **ID** (0–253). You daisy-chain them; the master talks to
  one ID at a time (or to all of them at once with the **broadcast ID `0xFE`**).
- **Set IDs one at a time.** A factory-fresh servo usually has ID 1. If you chain
  two servos that share an ID they will both answer and corrupt the bus. Connect
  **one new servo at a time**, give it a unique ID, then add the next.
- **Half-duplex single wire.** The servo's data line both receives commands and
  sends replies. A read is *command → turn the bus around → reply*. The BusLinker
  handles that turnaround for you; if you ever wire a servo straight to a bare
  UART you need direction-control hardware and precise timing.
- **One master only.** Two devices driving the same bus collide. During a read,
  give the servo time to answer before sending the next command (this library
  blocks for the reply, with a timeout).
- **Torque enable.** With torque **off** the servo is limp (free to backdrive) and
  ignores position targets — useful for hand-teaching poses or reading back where
  something was pushed. With torque **on** it holds/drives to the target. Call
  `enable_torque()` before expecting motion.
- **Position is a signed count, and center is 0.** Targets range roughly
  `-30719 … 30719`. `0` is the *calibrated center*. Use `write_pos_offset()` for a
  persistent zero trim, or `cali_pos()` to declare the current shaft angle as the
  new center.
- **Operating modes** (`select_mode`):
  - `POSITION_MODE` — go to and hold an absolute angle (normal servo behavior).
  - `CLOSED_LOOP_MOTOR_MODE` — continuous rotation at a regulated **speed**
    (signed; sign = direction). Set with `write_speed()`.
  - `OPEN_LOOP_MOTOR_MODE` — continuous rotation at a fixed **PWM duty**; actual
    speed varies with load. Set with `write_pwm_speed()`.
- **`acc` / `speed` limits.** In position moves, `acc` (0–254) shapes the
  acceleration ramp and `speed` (±3400) caps how fast it slews toward the target —
  smoother, quieter motion and less current spike than a bare position write.
- **Telemetry is free.** These servos report live **position, speed, load,
  current, voltage, temperature** and a moving flag. Watch temperature/current on
  a high-torque servo like the HX-65HM to catch overload before it faults.
- **`reg_write` + `action` = synchronized start.** A buffered `reg_write` (or
  `write_reg_pos_ex`) is *staged* but not executed until a single `reg_action()`
  (often broadcast) fires — so several joints begin moving on the same tick.
- **`sync_write` = one packet, many servos.** Update several servos in a single
  frame (`sync_write_pos_ex`) to save bus bandwidth and keep them in step.

---

## API reference

Construction & setup:

| Method | Description |
|---|---|
| `HXServo(HardwareSerial& s, uint32_t baud = 1000000)` | Bind to the UART wired to the bus. Does **not** open the port. |
| `void begin()` / `begin(uint32_t baud)` | Open the port (8N1). Call from `setup()`. |

Discovery & raw register access:

| Method | Description |
|---|---|
| `ping(id)` | Check a servo is online. `id = BROADCAST_ID` discovers a lone servo. |
| `general_write(id, addr, *data, len)` | Write raw bytes to a register (waits for ACK). |
| `general_read(id, addr, *data, len)` | Read raw bytes from a register. |
| `reg_write(id, addr, *data, len)` | Buffered write; applied by `reg_action()`. |
| `reg_action(id)` | Execute a buffered `reg_write` (broadcast to sync many servos). |
| `sync_write(addr, *data, len, param_len)` | Write a register block to many servos in one frame. |
| `sync_read(addr, byte_num, *ids, id_num, *data, *ok_mask = nullptr)` | Read a register block from many servos. `ok_mask` bit *i* reports whether `ids[i]` answered. |
| `flush_rx()` | Discard bytes left on the bus by a timed-out transaction. |

State & mode:

| Method | Description |
|---|---|
| `enable_torque(id)` / `disable_torque(id)` | Power the servo / let it free-wheel. |
| `cali_pos(id)` | Calibrate the current shaft angle as center. |
| `select_mode(id, mode)` | `POSITION_MODE` / `CLOSED_LOOP_MOTOR_MODE` / `OPEN_LOOP_MOTOR_MODE`. |

Motion (write). Values are clamped to the ranges shown:

| Method | Range | Description |
|---|---|---|
| `write_pos(id, pos)` | pos ∈ [-30719, 30719] | Set target position. |
| `write_pos_ex(id, acc, speed, pos)` | acc [0,254], speed [-3400,3400], pos [-30719,30719] | Position move with accel + speed limit. |
| `write_reg_pos_ex(id, acc, speed, pos)` | same | Buffered `write_pos_ex`; fires on `reg_action`. |
| `sync_write_pos_ex(rows[][4], n)` | rows of `{id, acc, speed, pos}`, n ≤ 30 | Position move for many servos in one frame. |
| `write_speed(id, speed)` | [-3400, 3400] | Target speed (closed-loop motor mode). |
| `write_pwm_speed(id, speed)` | [-1000, 1000] | PWM duty (open-loop motor mode). |
| `write_acc(id, acc)` | [0, 254] | Acceleration. |
| `write_pos_offset(id, offset)` | [-2047, 2047] | Persistent zero trim. |
| `write_max_torque(id, torque)` | [0, 1000] | Torque ceiling. |

Telemetry (read). Each returns a `ServoStatus_t` and writes through the pointer:

| Method | Out |
|---|---|
| `read_pos(id, &pos)` | present position |
| `read_speed(id, &speed)` | present speed |
| `read_pos_speed(id, &pos, &speed)` | both, one transaction |
| `read_load(id, &load)` | present load |
| `read_current(id, &cur)` | present current |
| `read_voltage(id, &vol)` | supply voltage (0.1 V/count) |
| `read_temperature(id, &temp)` | temperature (°C) |
| `read_moving_status(id, &status)` | 0 = stopped, 1 = moving |
| `read_pos_offset(id, &offset)` | stored zero trim |
| `sync_read_cur_pos_ex(ids, n, out[][5])` | rows of `{pos, speed, load, voltage, temp}` |

---

## Reading the `ServoStatus_t` result

Every call returns a `ServoStatus_t`. On full success `error_byte == 0` and, for
replies, `id` is the responding servo. Check specific flags:

```cpp
ServoStatus_t st = servo.read_pos(1, &pos);

if (st.error_bits.bit_tx)       { /* frame could not be sent          */ }
else if (st.error_bits.bit_rx)  { /* no / invalid reply (timeout)     */ }
else if (st.error_byte) {
    if (st.error_bits.bit_overheat) { /* servo over-temperature       */ }
    if (st.error_bits.bit_overload) { /* sustained overload           */ }
    if (st.error_bits.bit_voltage)  { /* supply voltage out of range  */ }
    // also: bit_sensor, bit_current, bit_angle
}
```

| Flag | Meaning |
|---|---|
| `bit_voltage` | Supply voltage out of range |
| `bit_sensor` | Angle / magnetic sensor fault |
| `bit_overheat` | Over-temperature |
| `bit_current` | Over-current |
| `bit_angle` | Commanded angle out of range |
| `bit_overload` | Sustained overload |
| `bit_tx` | *Driver:* frame failed to transmit |
| `bit_rx` | *Driver:* no/invalid reply within the timeout |

> `bit_tx` / `bit_rx` are raised by this library (transport problems); the other
> six are reported by the servo itself.

---

## Common recipes

**Discover an unknown servo's ID** (only one servo on the bus):
```cpp
ServoStatus_t st = servo.ping(BROADCAST_ID);
if (!st.error_bits.bit_rx) Serial.println(st.id);
```

**Hand-teach a pose, then read it back:**
```cpp
servo.disable_torque(1);            // limp — move it by hand
int16_t pos;
servo.read_pos(1, &pos);            // capture where you left it
```

**Move several joints in lock-step:**
```cpp
int16_t frame[3][4] = {   // {id, acc, speed, pos}
  {1, 50, 1000,  1500},
  {2, 50, 1000, -800 },
  {3, 50, 1000,  2048},
};
servo.sync_write_pos_ex(frame, 3);  // one packet, simultaneous motion
```

**Continuous rotation (wheel) at a set speed:**
```cpp
servo.select_mode(1, CLOSED_LOOP_MOTOR_MODE);
servo.enable_torque(1);
servo.write_speed(1, 1500);         // negative reverses direction
```

**Guard a high-torque servo against overload:**
```cpp
uint8_t temp; uint16_t cur;
servo.read_temperature(1, &temp);
servo.read_current(1, &cur);
if (temp > 65 /* °C */) servo.disable_torque(1);
```

---

## Troubleshooting

| Symptom | Likely cause |
|---|---|
| `ping` always times out (`bit_rx`) | Baud mismatch; TX/RX not crossed; no common GND; wrong UART; wrong ID. |
| Servo powered but won't move | Torque not enabled — call `enable_torque()`. |
| Two servos twitch / bus garbled | Duplicate IDs on the bus. Re-ID one at a time. |
| Works at 115200, fails at 1 Mbps | Wiring/length marginal at high baud, or the servo isn't set to 1 Mbps. Match all three. |
| Reads return zeros | The read timed out (`bit_rx` set) — check the status before trusting the value. |
| Big servo resets/browns out under load | Underpowered servo supply. Feed it from the BusLinker DC input, not the Arduino 5 V. |

Turn on `#define HX_DEBUG 1` in `HXServo.h` to see the exact bytes on the wire —
the fastest way to tell a wiring problem from a protocol problem.

---

## Changes from the original

This library is behavior-compatible with Hiwonder's `HX_30HM` reference, with the
following deliberate changes:

1. **Ported off ESP32.** The original constructor called `setRxBufferSize()` and
   the 4-argument `begin(baud, config, rx, tx)` — both ESP32-only and neither
   present on the UNO Q's STM32 core (or AVR). Serial start-up now lives in a
   portable `begin()` method using the standard `begin(baud, SERIAL_8N1)`, so the
   library compiles and runs on ordinary Arduino cores.
2. **`begin()` split out of the constructor.** Constructing a driver no longer
   opens the port. Call `servo.begin()` in `setup()` — the idiomatic, safe Arduino
   pattern (globals are constructed before the core is fully initialized).
3. **Renamed for the whole family.** `HX_30HM` → `HXServo`, `SerialServo` →
   `HXServo`, `HX_30HM_Def.h` → `HXServo_Registers.h`. The protocol is identical
   across the HX-HM family, so this is purely a naming clarification — the same
   class drives the **HX-65HM** and every other `*HM` model.
4. **Fixed the goal-speed field in `write_pos_ex` / `write_reg_pos_ex`.** The
   original wrote the *position* value into the goal-speed register (and
   `write_pos_ex` never even computed the speed), so the speed limit you passed was
   ignored. Both now compute and send the goal speed correctly. *(If you were
   relying on the original quirk, this is the one behavioral difference to be aware
   of.)*
5. **English documentation.** All in-code comments are rewritten in English, plus
   this README.
6. **Fixed `sync_read` (and therefore `sync_read_cur_pos_ex`).** Two defects made the
   original unusable, which is why callers had to fall back to one `general_read` per
   servo:
   - The request buffer was sized `1 + byte_num + id_num` but only `2 + id_num` bytes
     were ever filled, and `sizeof(buf)` was passed as the payload length. Every
     sync-read frame therefore carried uninitialised trailing bytes, which the servos
     parsed as **additional IDs to read** — producing phantom replies that desynchronised
     the bus.
   - Replies were stored by loop index, assuming they arrived in the order the IDs were
     listed. One silent servo shifted every later reply into the wrong slot, so a joint
     would silently report its neighbour's position. Replies are now filed by the ID
     they carry, a missing servo leaves a gap, and the optional `ok_mask` says which
     slots are valid.

   Both functions also flush the bus before and after a partial transaction so a late
   reply cannot corrupt the next one.
7. **Minor cleanups.** Removed a dead `#else` branch that referenced a nonexistent
   variable; error paths now clear outputs to `0` instead of assigning `NULL` to
   integer pointers; fixed the `read_temperture` → `read_temperature` typo; the
   debug flag is now `HX_DEBUG` (default **off**) and prints to a configurable
   `HX_DEBUG_STREAM`.

The register map, framing, checksum, and all command semantics are unchanged.

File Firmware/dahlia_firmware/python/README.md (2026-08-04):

# Dahlia Arm — Kinematics and Control

Host-side control for the 5-DOF Dahlia arm. Everything here runs on the Linux side; the
MCU only ever receives joint angles over SPI and never solves kinematics itself.

| File | Role |
| --- | --- |
| [`control/kinematics.py`](control/kinematics.py) | Closed-form forward and inverse kinematics |
| [`control/control.py`](control/control.py) | Controller input → end effector pose → joint targets |
| [`main.py`](main.py) | Poll the BLE controller, run the loop, push commands over SPI |

Units are millimetres and radians throughout.

---

## Part 1 — Kinematics

### The end effector

The end effector is the **tip of the wrist roll joint**. It sits exactly on the roll axis,
so roll spins the tool without moving the point: position and orientation decouple
completely, and the last joint drops out of the position problem entirely.

### Why this arm admits a closed form

The base yaws about the vertical. Shoulder, elbow and wrist pitch are all parallel to each
other and perpendicular to the base axis, so they form a planar 3R chain living in the
vertical plane the base selects. Wrist roll then spins the tool about its own approach
axis. No numerical solver, no iteration, no seed sensitivity.

### Task space is cylindrical, not Cartesian

Five degrees of freedom cannot reach an arbitrary 6-DOF pose — the approach axis is stuck
in whatever plane the base selects. So rather than accept Cartesian input and then check
whether it happens to be legal, this module uses the mechanism's own coordinates:

```
reach    distance from the base axis, in the arm plane    (mm)
height   above the root origin                            (mm)
yaw      of the arm plane, = the base joint               (rad)
pitch    of the approach axis, + is up                    (rad)
roll     about the approach axis, = the wrist roll joint  (rad)
```

This is the single biggest simplification over a Cartesian formulation, and it deletes
three separate sources of trouble rather than working around them:

- **No base-yaw branch.** `yaw` *is* the base joint, so there is nothing to invert. The
  old Cartesian version needed a second `θ_B ± π` branch with `r → −r`, `φ → π − φ`,
  `ψ → ψ − π`, and that reparameterization stopped being one-to-one for negative reach.
- **No base singularity.** At `reach = 0` a Cartesian `atan2(y, x)` is undefined; here
  yawing at zero reach just spins the base, which is perfectly well defined.
- **No out-of-plane test.** A pose that misses the reachable plane cannot be expressed in
  the first place, so there is no lateral-error check to run and no way to ask for one.

Only three numbers — reach, height, pitch — ever reach the solver. Yaw and roll are joints.

### Geometry

Every constant is measured off `dahlia_m1_full.urdf` by collapsing its fixed joints. Each
link is stored as a plain polar offset in its parent's frame — a length and the bend angle
it sits at when its joint reads zero:

```
base axis      offset  2.2324 mm along +x from the root origin
shoulder axis  height 83.5115 mm, meeting the base axis to within 1 µm
L1, B1  157.0616 mm,  2.9569172 rad    shoulder → elbow
L2, B2  175.7507 mm, −0.0009798 rad    elbow → wrist pitch
L3, B3   75.5005 mm, −0.0005102 rad    wrist pitch → end effector
approach axis, −0.0038214 rad off the wrist pitch frame
sideways offset of the end effector from the arm plane, 0.4502 mm
```

Only `B1` is a design feature — the upper arm is a bent casting. `B2`, `B3` and the
approach tilt are sub-0.06° assembly asymmetries in the CAD export; they are kept because
carrying them costs nothing (every link already has a bend term) and it makes the model
reproduce the URDF exactly instead of approximately.

The sideways offset deserves a note: the individual joint axes sit 15–34 mm off the arm
plane, but those offsets **cancel down the chain** to 0.45 mm at the end effector. That is
what makes the planar decomposition legitimate. Since no planar joint can change it, it is
a rigid sideways shift of the whole arm and only appears when converting to Cartesian.

### Forward kinematics

Each link's absolute angle in the arm plane is just the sum of the joints before it:

```
a₁ = θ_S + B₁
a₂ = θ_S + θ_E + B₂
a₃ = θ_S + θ_E + θ_WP + B₃

reach  =          L₁cos a₁ + L₂cos a₂ + L₃cos a₃
height = 83.5115 + L₁sin a₁ + L₂sin a₂ + L₃sin a₃
pitch  = θ_S + θ_E + θ_WP − 0.0038214
yaw    = θ_B                    roll = θ_WR
```

### Inverse kinematics

```
Σ   = pitch + 0.0038214                       # θ_S + θ_E + θ_WP
w   = (reach, height − 83.5115) − L₃·u(Σ + B₃)   # step back to the wrist pitch centre
cos c = (|w|² − L₁² − L₂²) / (2 L₁ L₂)        # law of cosines on the remaining 2R
θ_E = ±c + B₁ − B₂
θ_S = atan2(w_h, w_r) − atan2(L₂ sin c, L₁ + L₂ cos c) − B₁
θ_WP = Σ − θ_S − θ_E                          # wrist pitch just closes the sum
```

`|cos c| > 1` means the wrist centre is outside the annulus the two links can span. The
two signs of `c` are the elbow-up and elbow-down branches, which is the *only* remaining
multiplicity — at most **two** solutions, down from four.

### Two implementation traps

Both matter if this is ever ported to firmware:

1. **Don't wrap angles into [−π, π].** Shoulder and elbow travel past ±π (−3.375 and
   +3.451 rad), so naive wrapping silently discards valid solutions. `_fit_limits()`
   shifts each angle by the multiple of 2π nearest the middle of its own limit range
   instead. Every limit spans less than 2π, so one shift is always enough.
2. **Guard the arccos argument at both ends.** Near full extension it drifts a hair past
   1.0 from floating point. A strict `> 1.0` rejection would refuse legitimate
   full-extension poses, and no rejection at all returns NaN — so the range check carries
   a 1e-9 tolerance and the argument is then clipped before `arccos` sees it.

### Verification against the URDF

The model is checked against a numeric FK built straight from the URDF, over 5 000 random
in-limit configurations:

```
end effector position error   max 0.0037 mm
approach axis error           max 0.00068 deg
roll joint rotation           max 5.9e-15 rad
```

For comparison, the previous model — which used rounded link lengths, ignored the 2.2 mm
base offset and ignored the 0.45 mm sideways offset — was **2.27 mm mean, 3.19 mm max**
against the same reference. The rewrite is effectively exact.

`python control/kinematics.py` runs the round trip over 20 000 random in-limit configs:

```
original joint vector among the branches: 20000/20000
worst task pose error of fk(ik(pose)):    3.98e-13
worst point error of fk(ik(pose)):        4.02e-13 mm
most simultaneous solutions:              2
```

### Workspace

Straight out, the arm reaches `L₁ + L₂ + L₃ = 408.3 mm`. Within joint limits the envelope
is roughly 408 mm of reach and −231 … +492 mm of height.

Pitch range available with the end effector point held fixed, sampled on a grid:

| reach | height 0 | 100 | 200 | 300 |
| --- | --- | --- | --- | --- |
| 120 mm | 67° | 108° | 129° | 129° |
| 200 mm | 87° | 112° | 129° | 129° |
| 280 mm | 108° | 125° | 129° | 120° |
| 350 mm | 125° | 139° | 111° | unreachable |

This is what putting the end effector at the wrist roll tip buys. When the tool tip was
99 mm further out, holding it fixed forced the wrist centre onto a 174 mm arc that the
shoulder and elbow had to produce, and from the home pose *no* positive pitch solved at
all. At 75.5 mm the arc is small enough that pitch is simply a free axis nearly everywhere,
so the controller can treat it as a pure rotation with no compensation trickery.

---

## Part 2 — Control System

### Input mapping

| Input | Effect |
| --- | --- |
| Joystick X | Height — straight up and down in the root frame |
| Joystick Y | Reach — along the direction the base plate points |
| Joystick button (**hold**) | Gyroscopic following |
| ↳ controller roll | Arm yaw |
| ↳ controller pitch | Approach pitch |
| Rotary encoder (**turn**) | Roll about the approach axis |
| Encoder button (**click**) | Snaps the clamp fully open / fully closed |
| **Both buttons** | Freeze and return to the startup pose |

Because the task space is already cylindrical, both stick axes are one-line increments:

```python
pose[HEIGHT] += axis(joy_x) * HEIGHT_RATE * PERIOD
pose[REACH]  += axis(joy_y) * REACH_RATE  * PERIOD
```

**Joystick X is absolute**, in the root frame — pure vertical motion regardless of where
the tool points. **Joystick Y follows the yaw only** — it moves along the base plate's
heading, and the tool's pitch and roll never steer it. Measured across three start poses
(yaw 0°/+34°/−46°, pitch +40°/−23°/+69°, roll 0°/+52°/−63°) and both directions, every tick
is a clean 7.00 mm step with **off-axis motion below 1e-13 mm and zero pitch drift**.

**The joystick is a switch, not a proportional axis.** Past `JOY_THRESHOLD` (800 counts)
the axis commands full rate; below it, nothing. Short corrections land predictably instead
of depending on how far the stick was pushed.

### Reachability is the guard

There are no hand-tuned reach or height boxes. Each coordinate is applied **one at a time**
and kept only if the resulting pose still solves:

```python
for coordinate in (YAW, ROLL, REACH, HEIGHT, PITCH):
    trial = list(self.pose)
    trial[coordinate] = pose[coordinate]
    solution = self._solve(trial)

    if solution is not None:
        self.pose, self.target = trial, solution
```

Per coordinate rather than all-or-nothing, so an unreachable pitch cannot veto the
translation asked for in the same tick — each axis stops where the workspace ends while the
others keep moving. Measured: driven to the reach limit, reach pins at 284.3 mm while
height still moves freely. Because the commanded pose is never allowed to leave the
reachable set, it also cannot wind up, so no clamping is needed to bound it.

Yaw and roll are clamped directly to their joint limits instead, since each maps to exactly
one joint and the mapping is exact.

### Gyroscopic following

While the joystick button is held, controller **roll** drives the arm's yaw and controller
**pitch** drives the approach pitch. With 5 DOF the approach axis must lie in the plane the
base selects, so "yaw" necessarily means rotating the base, carrying the end effector
around at constant reach and height. Roll about the approach axis stays on the encoder.

Following is **relative**: on engage, the controller attitude *and* the committed pose are
captured as a reference, and only the delta is applied. So engaging never jumps, the
controller can be released and repositioned freely, and gyro drift is shed on every press
instead of accumulating. Measured: **0.0000 rad jump** on engage, on release, and on
re-engage after moving the controller 90°+ on two axes; +30° of controller roll gives
+30.000° of yaw, −25° of controller pitch gives −25.000° of pitch, neither touching the
other.

The delta is applied **absolutely against the reference** rather than integrated. A pitch
the arm cannot reach is simply not taken, and is picked up again on the way back, instead
of winding up an offset while it is being refused.

Pitch is a **pure rotation** — the end effector point does not move. Measured 5.7e-14 mm of
translation across a 75° pitch sweep. The old code had to shove reach and height around to
fake rotation about the wrist centre, and then undo that shove when the pose was rejected;
with the end effector at the roll tip, none of that is needed.

### Roll on the encoder

Encoder counts integrate into roll at `ROLL_PER_COUNT` (0.08 rad ≈ 4.6° per count) and
clamp at the joint limit. Integrating deltas rather than mapping absolutely is what gives
the **moving extrema**: once roll saturates, turning back moves it on the very next count
instead of waiting for the encoder to wind back to wherever it first hit the stop.
Measured: 10 counts gives +45.84°, spinning far past the stop saturates at exactly the
+83.480° limit, and a single count back drops it to +78.896°.

Counts are consumed every tick and banked by none, so a tick that ignores input (homing, or
a stalled joint) discards the motion that happened during it rather than applying it later
in a lump.

### Clamp

The encoder button snaps the clamp fully open or fully closed. It toggles on **release**
rather than press, which is what lets the two-button gesture cancel it: pressing both
buttons in either order starts homing and leaves the clamp untouched. No operator presses
two buttons on exactly the same 50 ms tick, so a press-triggered clamp would flip on the
way into every homing gesture. Verified both orders.

### Return to the startup pose

Pressing **both buttons** freezes everything and walks the arm back to the configuration it
was in at startup, captured once on the first seed so it always means the same place.
While homing:

- every input is ignored — joystick, gyro, encoder and clamp alike;
- the commanded pose is not touched, so nothing changes underneath the operator;
- the gyro reference is dropped and encoder counts are discarded, so nothing that happened
  during homing leaks out afterwards.

It ends when the *measured* joints are all within `HOME_TOLERANCE` (0.05 rad) of the
startup pose, at which point the task pose is re-synced from it and control resumes.
Verified: pose constant for every tick of homing, clamp unchanged, no banked encoder
motion, and against an arm slewing at 2 rad/s it settles in 9 ticks (0.45 s).

`HOME_TIMEOUT` (10 s) is a deliberate escape hatch rather than part of the gesture: a joint
that will never arrive would otherwise leave the arm permanently uncommandable. It prints
when it fires. Homing itself stays available even when a joint is stalled, so it is also
the way out of a stall.

### Safety layer

1. **Rate limit.** Steps are capped at `MAX_JOINT_STEP` (0.25 rad/tick ≈ 5 rad/s at 20 Hz,
   matching the velocity ceiling sent to the MCU). The whole step vector is **scaled**, not
   clipped per joint — clipping one joint but not the others changes their ratio and walks
   the end effector off the commanded path. Measured peak 0.185 rad/tick = 3.71 rad/s.

2. **Leash to the measured arm.** Each commanded joint is held within `MAX_JOINT_ERROR`
   (1.20 rad) of its measured angle. A leash cannot latch the way a freeze does: the
   command tracks alongside the measured angle, so the error closes the moment the joint
   frees up. While any joint is leashed the task pose is frozen, so it cannot wander off
   from the hardware and drag the other four joints toward a pose that will never happen.
   Leashed joints are named on stdout at most every 2 s.

   Measured against a dead base servo: the command holds at exactly 1.20 rad away, the task
   pose drifts 0.00, and both recover on their own once the joint is freed.

3. **Joint limit clamp** as a backstop. 0 violations over 4 000 randomized ticks.

On headroom: a 5 rad/s arm tracks with 0.000 rad of error. Driven adversarially — full
random stick and gyro input every single tick — a 2 rad/s arm peaks at 1.100 rad and a
1 rad/s arm at 1.150 rad, so the leash does engage briefly under abuse on a slow or heavily
loaded arm. That is the mechanism working as intended, not a fault, but if a loaded arm
nuisance-trips it on the bench, lower `MAX_JOINT_STEP` to match what the servos can
actually deliver rather than raising `MAX_JOINT_ERROR`.

Joint velocity sent to the MCU is a constant `JOINT_VEL = 5.0` rad/s. It is a slew
*ceiling*, not a speed setting — actual speed comes from how fast the targets move. Sending
a velocity at or below the demanded rate starves the MCU's rate limiter and causes windup.

### Data flow

```
SEC controller (BLE)
  → controller_service  :8000/controller     (JSON controller state)
    → main.py           20 Hz loop
      → control.py      pose update → IK → rate limit → joint targets
        → spi_service   :9000/targets        (HTTP)
          → SPI brick   100 Hz full-duplex exchange
            → MCU       200 Hz servo loop
              ← feedback: measured joints, status, per-joint fault bytes
```

Feedback returns on the same SPI transaction that carries the command. `main.py` seeds the
task pose from measured joints at startup, so the first command never jumps, and re-seeds
if the SPI service drops out. Re-seeding does **not** move the homing target.

### Tuning constants

All in [`control.py`](control.py):

| Constant | Default | Meaning |
| --- | --- | --- |
| `JOY_THRESHOLD` | 800 counts | Stick travel before an axis engages; no ramp above it |
| `REACH_RATE` | 140 mm/s | Jog speed along the base heading |
| `HEIGHT_RATE` | 140 mm/s | Jog speed, vertical |
| `ROLL_PER_COUNT` | 0.08 rad | Approach roll per encoder count |
| `JOY_SIGNS` | (1, 1) | Per-axis flip for joystick X / Y |
| `GYRO_SIGNS` | (1, 1) | Per-axis flip for controller roll / pitch |
| `MAX_JOINT_STEP` | 0.25 rad | Per-tick rate limit (≈ 5 rad/s at 20 Hz) |
| `MAX_JOINT_ERROR` | 1.20 rad | Leash distance from the measured arm |
| `HOME_TOLERANCE` | 0.05 rad | Per-joint error that counts as settled at home |
| `HOME_TIMEOUT` | 10 s | Escape hatch if a joint never arrives |

### Control verification

47 behavioural checks against a simulated arm, all passing:

```
joystick X, 3 poses x 2 directions   7.00 mm/tick vertical, off-axis < 1e-13 mm, 0 pitch drift
joystick Y, 3 poses x 2 directions   7.00 mm/tick along heading, off-heading < 1e-13 mm
joystick threshold                   799 -> 0.0, 801 -> 1.0, -900 -> -1.0  (no ramp)
encoder click                        clamp byte toggles 0 / 255 on each click
encoder turn                         10 counts -> +45.84 deg
roll extrema                         saturates at +83.480 deg, one count back -> +78.896
gyro engage / release / re-engage    0.0000 rad jump in all three
gyro roll -> yaw                     +30 deg controller -> +30.000 deg arm, pitch untouched
gyro pitch -> pitch                  -25 deg controller -> -25.000 deg arm, yaw untouched
gyro pitch is a pure rotation        point moves 5.7e-14 mm over a 75 deg sweep
both buttons                         homes, re-syncs, clamp untouched, pose constant throughout
press order                          neither order flips the clamp
homing vs a 2 rad/s arm              settles in 9 ticks (0.45 s)
workspace edge                       reach pins at 284.3 mm, height still free
stalled joint                        command holds at exactly 1.20 rad, pose drift 0.00
stall recovery                       recovers unaided, control resumes
rate limiting                        peak 0.185 rad/tick = 3.71 rad/s
fk(target) vs commanded pose         agrees to 1.1e-13
joint limit violations               0 / 4000 randomized ticks
```

Hardware behaviour is unverified — `JOY_SIGNS`, `GYRO_SIGNS` and `ROLL_PER_COUNT` in
particular are best confirmed on the bench.

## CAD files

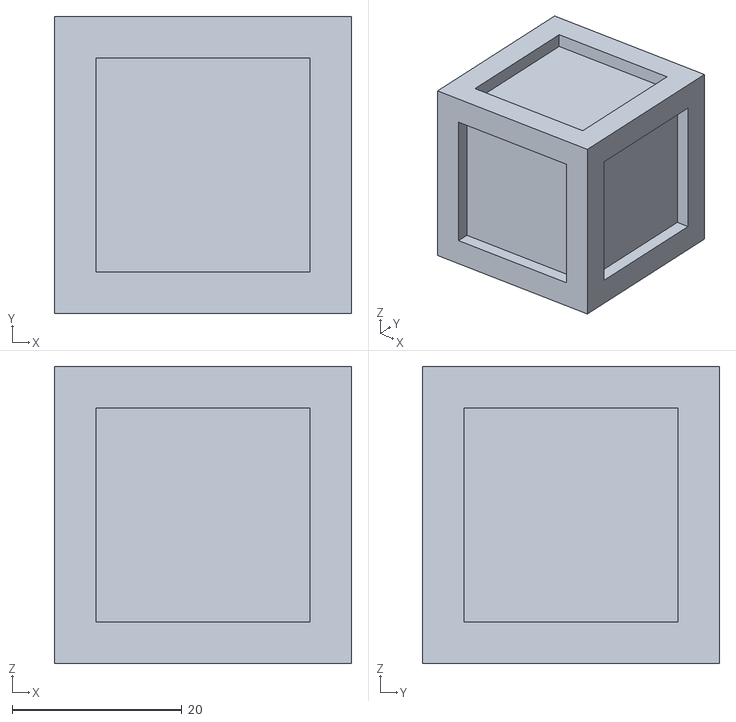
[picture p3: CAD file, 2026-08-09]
Extras/microtag_block/MicroTag Block.stl
35.0 x 35.0 x 35.0

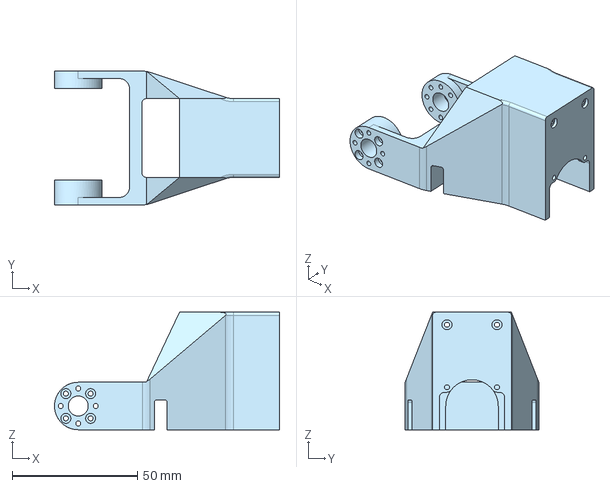
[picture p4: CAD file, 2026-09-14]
Hardware/dahlia_hardware/arm/arm_wrist.step
90.0 x 53.5 x 47.0 mm

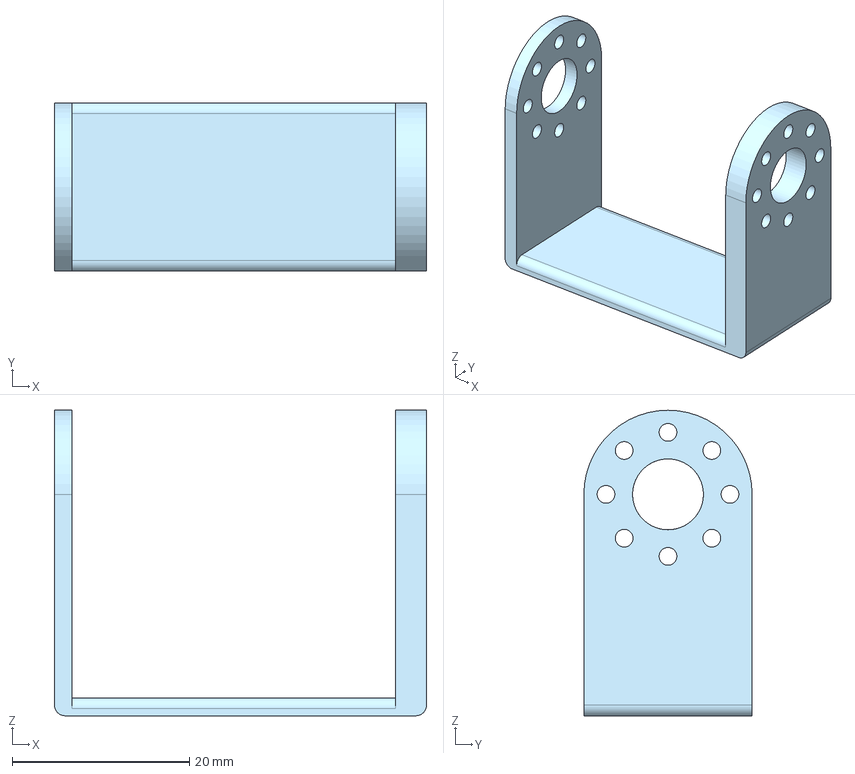
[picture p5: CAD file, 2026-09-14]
Hardware/dahlia_hardware/base/base_rotation_bracket.step
42.0 x 19.0 x 34.5 mm

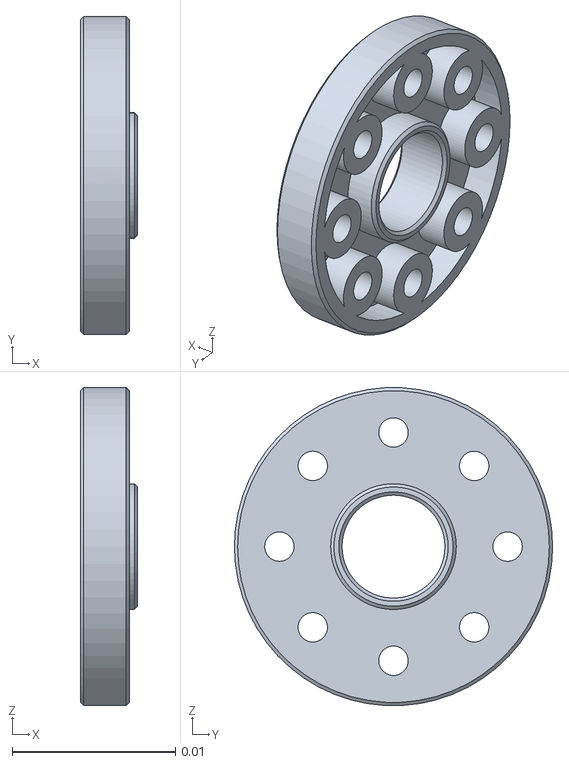
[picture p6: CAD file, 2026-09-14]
Hardware/dahlia_hardware/dahlia_m1_full/meshes/servo_horn_8hole.stl
0.0035 x 0.0195 x 0.0195

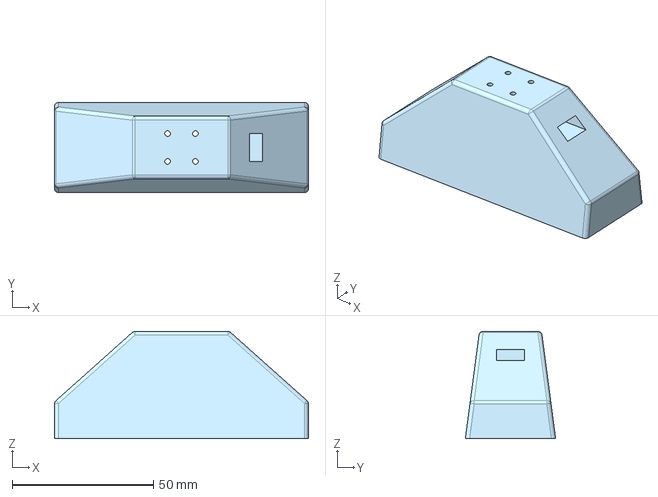
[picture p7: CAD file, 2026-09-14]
Hardware/dahlia_hardware/end_effector/ef_body.step
90.0 x 32.0 x 38.0 mm

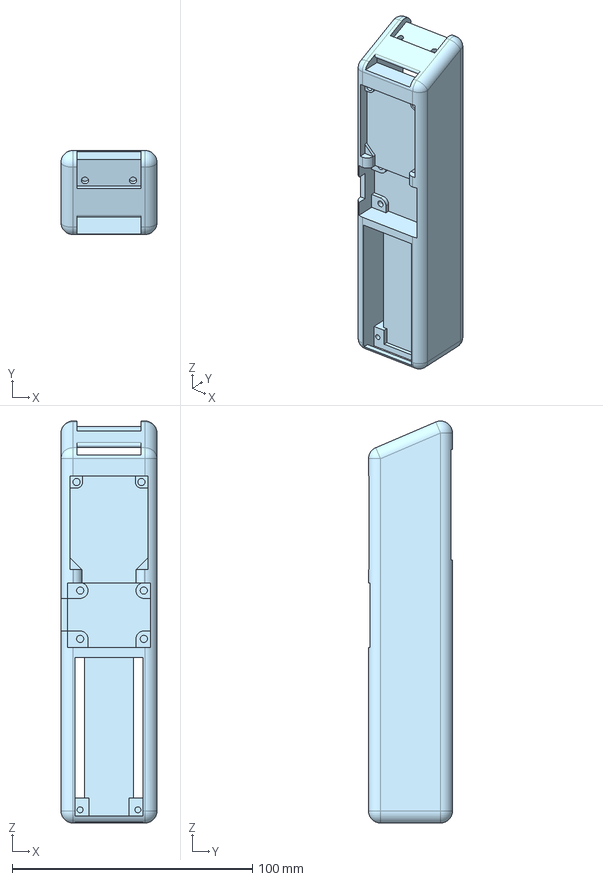
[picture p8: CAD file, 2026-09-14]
Hardware/sec_hardware/sec_body.step
40.0 x 35.0 x 167.4 mm

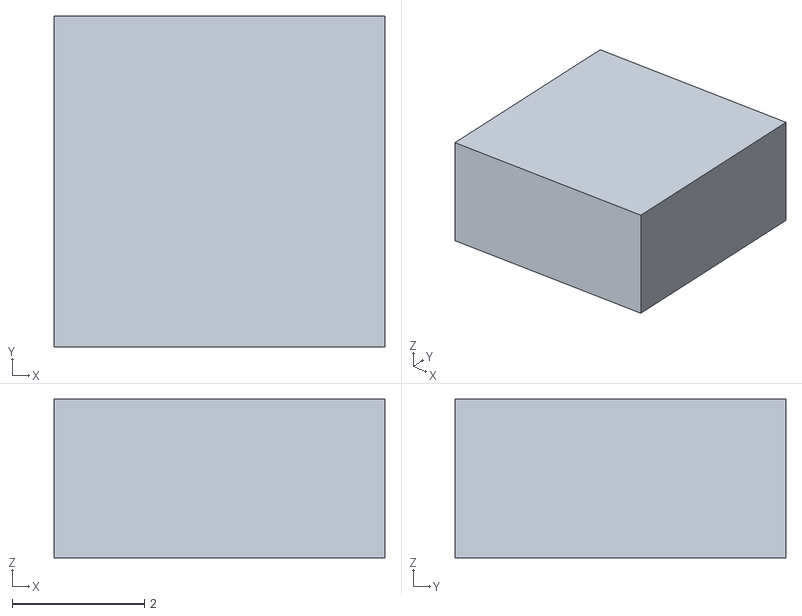
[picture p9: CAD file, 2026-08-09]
Extras/microtag_block/MicroTag Piece.stl
5.00 x 5.00 x 2.40

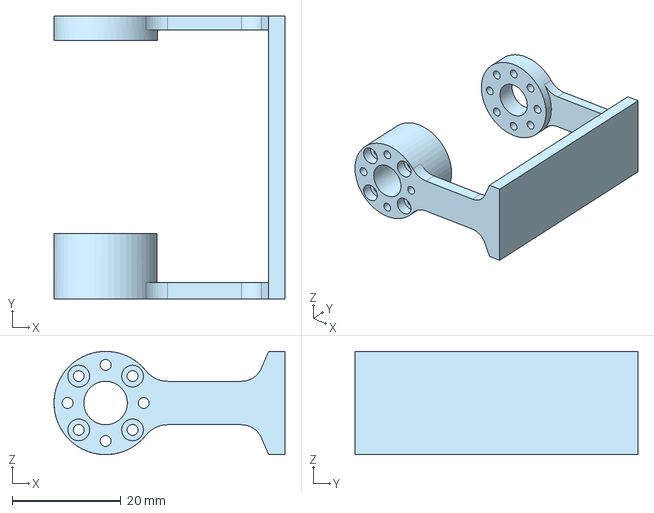
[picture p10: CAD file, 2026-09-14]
Hardware/dahlia_hardware/arm/arm_wrist_rotation.step
42.5 x 52.0 x 19.0 mm

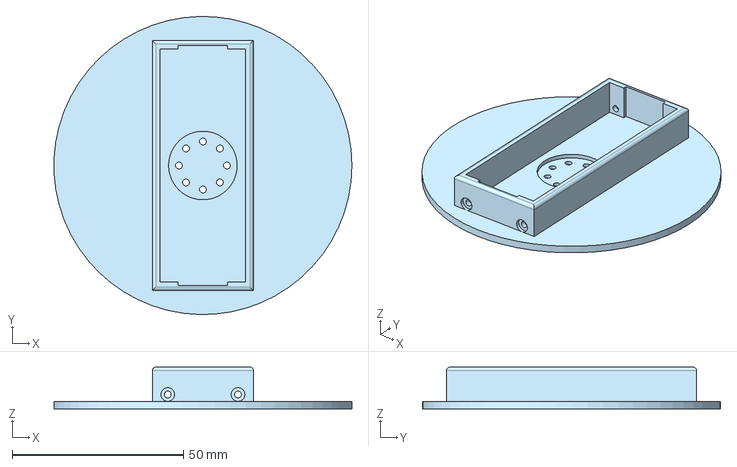
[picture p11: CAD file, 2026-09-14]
Hardware/dahlia_hardware/base/base_rotation_plate.step
86.9 x 87.0 x 12.2 mm

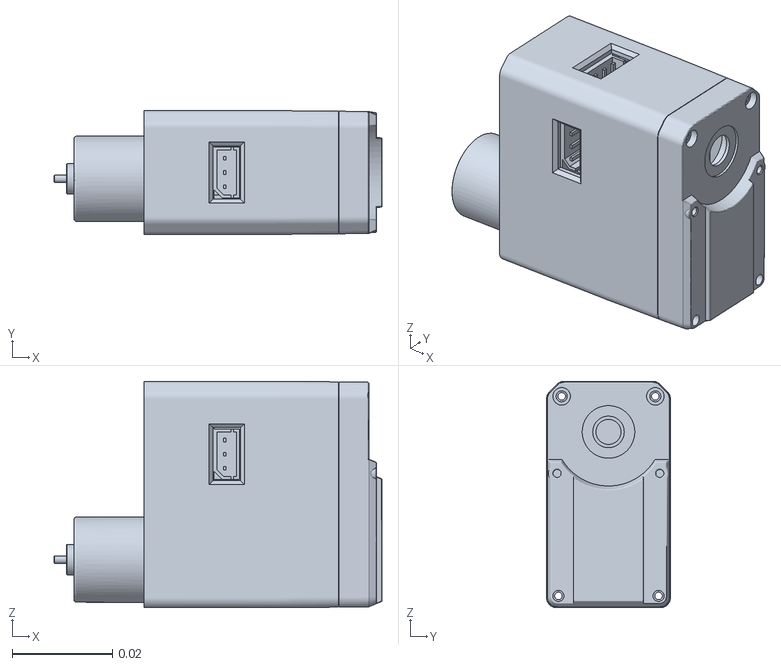
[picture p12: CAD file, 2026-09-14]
Hardware/dahlia_hardware/dahlia_m1_full/meshes/servo_hx65_partb.stl
0.0655 x 0.0247 x 0.0452

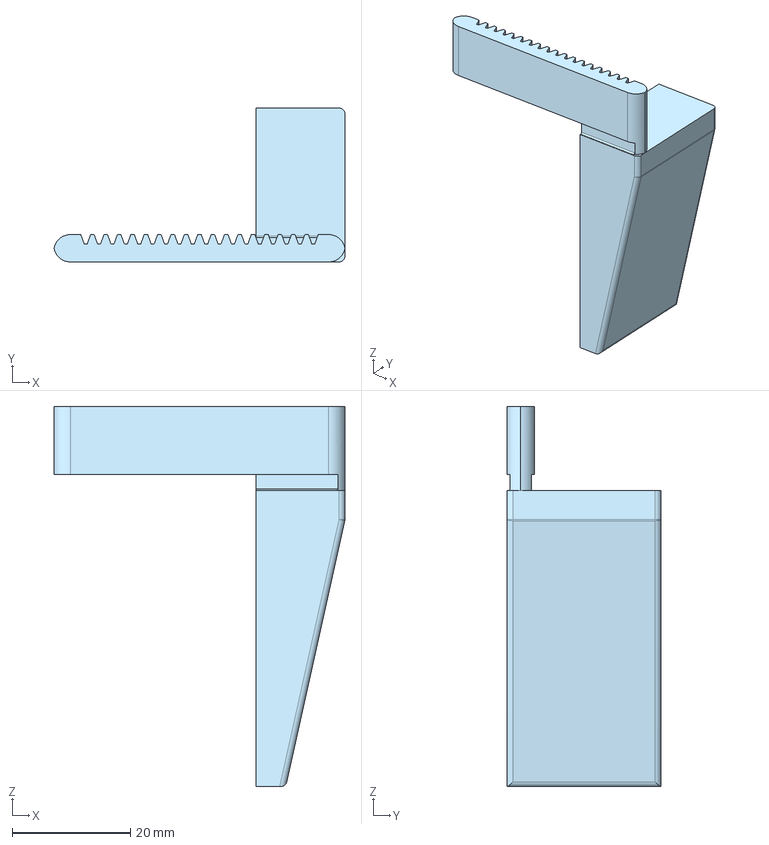
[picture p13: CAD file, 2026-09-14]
Hardware/dahlia_hardware/end_effector/ef_clamp.step
49.2 x 26.0 x 64.2 mm

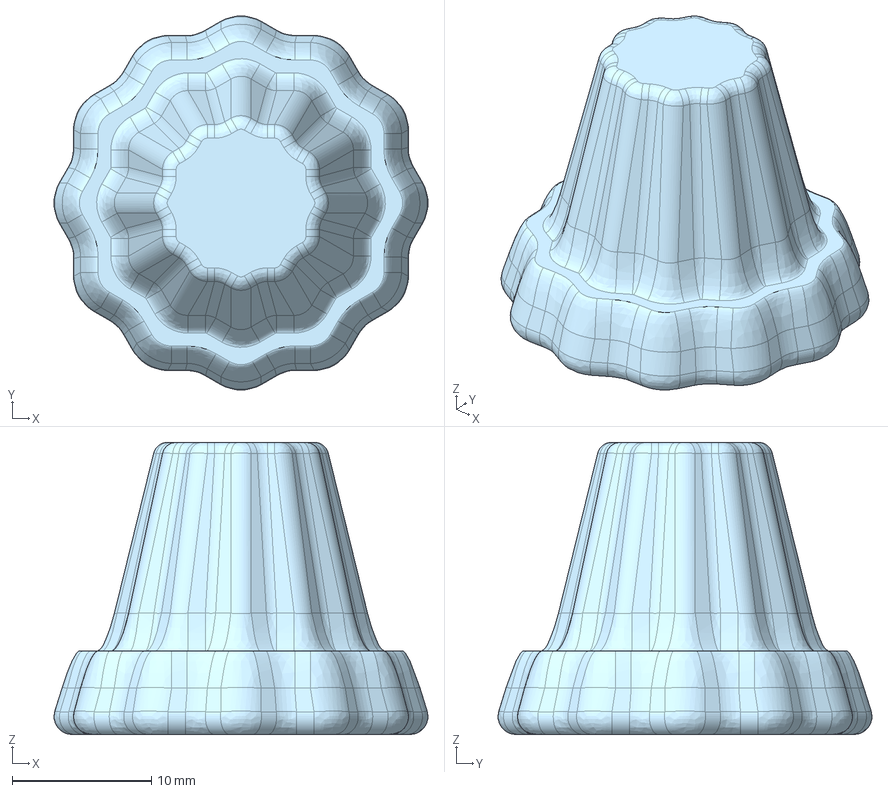
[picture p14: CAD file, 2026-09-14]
Hardware/sec_hardware/sec_encoder_knob.step
26.9 x 26.9 x 21.0 mm

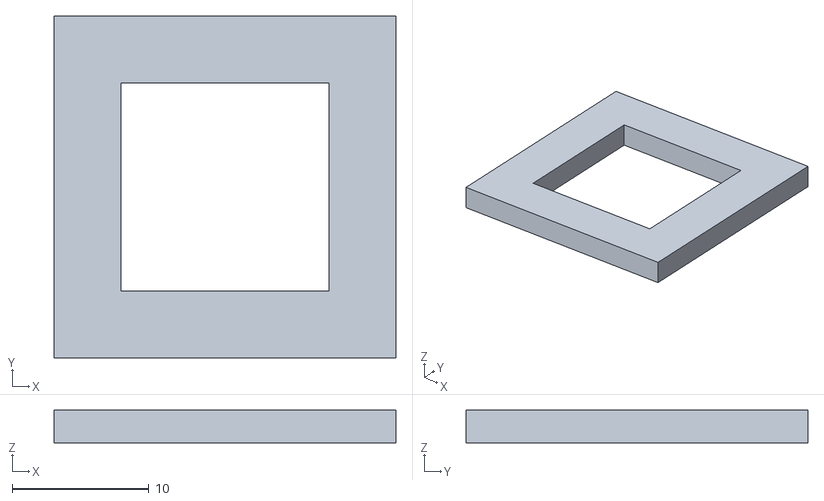
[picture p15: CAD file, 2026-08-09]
Extras/microtag_block/MicroTag Frame.stl
25.0 x 25.0 x 2.40

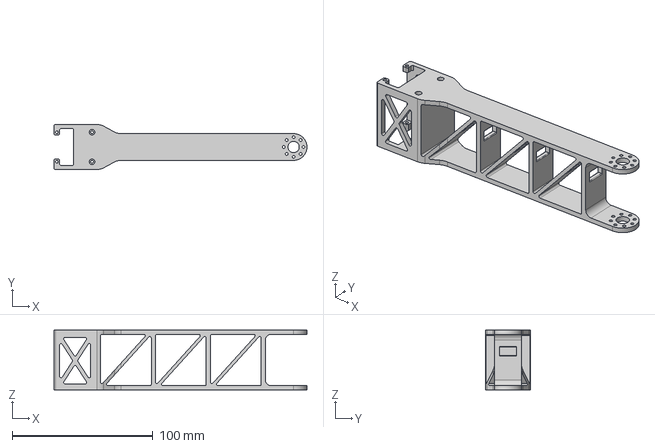
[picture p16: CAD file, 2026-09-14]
Hardware/dahlia_hardware/arm/arm_lower_arm.step
179.5 x 32.0 x 42.5 mm

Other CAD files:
Hardware/dahlia_hardware/base/base_body.step
Hardware/dahlia_hardware/dahlia_m1_full/meshes/servo_hx65_partc.stl
Hardware/dahlia_hardware/end_effector/ef_gear.step
Hardware/dahlia_hardware/arm/arm_upper_arm.step
Hardware/dahlia_hardware/base/base_servo_mount.step
Hardware/dahlia_hardware/dahlia_m1_full/meshes/arm_lower_arm.stl
Hardware/dahlia_hardware/dahlia_m1_full/meshes/arm_upper_arm.stl
Hardware/dahlia_hardware/dahlia_m1_full/meshes/arm_wrist.stl
Hardware/dahlia_hardware/dahlia_m1_full/meshes/arm_wrist_bracket.stl
Hardware/dahlia_hardware/dahlia_m1_full/meshes/base_body.stl
Hardware/dahlia_hardware/dahlia_m1_full/meshes/base_rotation_bracket.stl
Hardware/dahlia_hardware/dahlia_m1_full/meshes/base_rotation_plate.stl
Hardware/dahlia_hardware/dahlia_m1_full/meshes/base_servo_mount.stl
Hardware/dahlia_hardware/dahlia_m1_full/meshes/ef_body.stl
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

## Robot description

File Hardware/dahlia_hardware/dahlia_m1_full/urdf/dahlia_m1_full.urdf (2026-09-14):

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
<robot name="dahlia_m1_full">
    <link name="arm_lower_arm">
        <inertial>
            <mass value="4.03277e-05" />
            <origin xyz="-0.0929725 -1.09541e-11 0.0180773" rpy="0 -0 0" />
            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
        </inertial>
        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
    </link>
    <link name="arm_upper_arm">
        <inertial>
            <mass value="5.94503e-05" />
            <origin xyz="0.0378335 0.0791237 -0.000373111" rpy="0 -0 0" />
            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
        </inertial>
        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
    </link>
    <link name="arm_wrist">
        <inertial>
            <mass value="3.76971e-05" />
            <origin xyz="0.0414392 -0.0200523 0.0105969" rpy="0 -0 0" />
            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
        </inertial>
        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
    </link>
    <link name="arm_wrist_bracket">
        <inertial>
            <mass value="7.31589e-06" />
            <origin xyz="0.0155661 -0.0252608 3.46945e-18" rpy="0 -0 0" />
            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
        </inertial>
        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
    </link>
    <link name="base_body">
        <inertial>
            <mass value="0.000154731" />
            <origin xyz="3.08329e-17 -0.00195719 0.0141649" rpy="0 -0 0" />
            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
        </inertial>
        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
    </link>
    <link name="base_rotation_bracket">
        <inertial>
            <mass value="4.33021e-06" />
            <origin xyz="0.0221861 -3.8125e-20 -0.0143146" rpy="0 -0 0" />
            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
        </inertial>
        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
    </link>
    <link name="base_rotation_plate">
        <inertial>
            <mass value="1.68084e-05" />
            <origin xyz="8.45373e-18 -1.59414e-18 0.00258928" rpy="0 -0 0" />
            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
        </inertial>
        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
    </link>
    <link name="base_servo_mount">
        <inertial>
            <mass value="7.4708e-06" />
            <origin xyz="0.018 0.0111648 0.00365535" rpy="0 -0 0" />
            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
        </inertial>
        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
    </link>
    <link name="ef_body">
        <inertial>
            <mass value="4.86531e-05" />
            <origin xyz="0.000991138 2.72244e-15 -0.0213282" rpy="0 -0 0" />
            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
        </inertial>
        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
    </link>
    <link name="ef_clamp">
        <inertial>
            <mass value="1.5949e-05" />
            <origin xyz="-0.0113693 0.00909521 -0.0307162" rpy="0 -0 0" />
            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
        </inertial>
        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
    </link>
    <link name="ef_clamp_1">
        <inertial>
            <mass value="1.5949e-05" />
            <origin xyz="-0.0113693 0.00909521 -0.0307162" rpy="0 -0 0" />
            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
        </inertial>
        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
    </link>
    <link name="ef_front_cap">
        <inertial>
            <mass value="4.65192e-06" />
            <origin xyz="0.038 -2.96302e-19 -0.000836364" rpy="0 -0 0" />
            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
        </inertial>
        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
    </link>
    <link name="ef_gear">
        <inertial>
            <mass value="1.26348e-06" />
            <origin xyz="-1.60107e-11 -3.31849e-05 9.69975e-14" rpy="3.14159 -0.00608539 3.14159" />
            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
        </inertial>
        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
    </link>
    <link name="ef_servo">
        <inertial>
            <mass value="6.80996e-06" />
            <origin xyz="-3.18749e-15 -0.0049728 0.0126507" rpy="0 -0 0" />
            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
        </inertial>
        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
    </link>
    <link name="mate_connector_1">
        <inertial>
            <mass value="1e-09" />
            <origin xyz="0 0 0" rpy="0 -0 0" />
            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
        </inertial>
    </link>
    <link name="mate_connector_10">
        <inertial>
            <mass value="1e-09" />
            <origin xyz="0 0 0" rpy="0 -0 0" />
            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
        </inertial>
    </link>
    <link name="mate_connector_12">
        <inertial>
            <mass value="1e-09" />
            <origin xyz="0 0 0" rpy="0 -0 0" />
            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
        </inertial>
    </link>
    <link name="mate_connector_2">
        <inertial>
            <mass value="1e-09" />
            <origin xyz="0 0 0" rpy="0 -0 0" />
            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
        </inertial>
    </link>
    <link name="mate_connector_3">
        <inertial>
            <mass value="1e-09" />
            <origin xyz="0 0 0" rpy="0 -0 0" />
            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
        </inertial>
    </link>
    <link name="mate_connector_4">
        <inertial>
            <mass value="1e-09" />
            <origin xyz="0 0 0" rpy="0 -0 0" />
            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
        </inertial>
    </link>
    <link name="mate_connector_5">
        <inertial>
            <mass value="1e-09" />
            <origin xyz="0 0 0" rpy="0 -0 0" />
            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
        </inertial>
    </link>
    <link name="mate_connector_6">
        <inertial>
            <mass value="1e-09" />
            <origin xyz="0 0 0" rpy="0 -0 0" />
            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
        </inertial>
    </link>
    <link name="mate_connector_7">
        <inertial>
            <mass value="1e-09" />
            <origin xyz="0 0 0" rpy="0 -0 0" />
            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
        </inertial>
    </link>
    <link name="mate_connector_8">
        <inertial>
            <mass value="1e-09" />
            <origin xyz="0 0 0" rpy="0 -0 0" />
            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
        </inertial>
    </link>
    <link name="mate_connector_9">
        <inertial>
            <mass value="1e-09" />
            <origin xyz="0 0 0" rpy="0 -0 0" />
            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
        </inertial>
    </link>
    <link name="mateconnector_ef_gear">
        <inertial>
            <mass value="1e-09" />
            <origin xyz="0 0 0" rpy="0 -0 0" />
            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
        </inertial>
    </link>
    <link name="root" />
    <link name="servo_horn_4hole">
        <inertial>
            <mass value="1.01782e-06" />
            <origin xyz="-0.00151552 -2.60463e-09 -1.24222e-08" rpy="0 -0 0" />
            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
        </inertial>
        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
    </link>
    <link name="servo_horn_4hole_1">
        <inertial>
            <mass value="1.01782e-06" />
            <origin xyz="-0.00151552 2.55715e-09 1.24321e-08" rpy="-3.13777 -0 0" />
            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
        </inertial>
        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
    </link>
    <link name="servo_horn_4hole_2">
        <inertial>
            <mass value="1.01782e-06" />
            <origin xyz="-0.00151552 -2.60463e-09 -1.24222e-08" rpy="0 -0 0" />
            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
        </inertial>
        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
    </link>
    <link name="servo_horn_4hole_3">
        <inertial>
            <mass value="1.01782e-06" />
            <origin xyz="-0.00151552 -2.53859e-09 -1.24359e-08" rpy="0.00531345 -0 0" />
            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
        </inertial>
        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
    </link>
    <link name="servo_horn_4hole_4">
        <inertial>
            <mass value="1.01782e-06" />
            <origin xyz="-0.00151552 -2.60463e-09 -1.24222e-08" rpy="0 -0 0" />
            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
        </inertial>
        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
    </link>
    <link name="servo_horn_4hole_5">
        <inertial>
            <mass value="1.01782e-06" />
            <origin xyz="0.00198448 4.13442e-12 3.90456e-10" rpy="0 -0 0" />
            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
        </inertial>
        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
    </link>
    <link name="servo_horn_8hole">
        <inertial>
            <mass value="5.35885e-07" />
            <origin xyz="-0.00128071 6.01143e-11 6.67043e-10" rpy="0 -0 0" />
            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
        </inertial>
        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
    </link>
    <link name="servo_horn_8hole_1">
        <inertial>
            <mass value="5.35885e-07" />
            <origin xyz="-0.00128071 6.01143e-11 6.67043e-10" rpy="0 -0 0" />
            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
        </inertial>
        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
    </link>
    <link name="servo_horn_8hole_2">
        <inertial>
            <mass value="5.35885e-07" />
            <origin xyz="-0.00128071 6.01143e-11 6.67043e-10" rpy="0 -0 0" />
            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
        </inertial>
        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
    </link>
    <link name="servo_horn_8hole_3">
        <inertial>
            <mass value="5.35885e-07" />
            <origin xyz="-0.00128071 6.01143e-11 6.67043e-10" rpy="0 -0 0" />
            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
        </inertial>
        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
    </link>
    <link name="servo_hx30">
        <inertial>
            <mass value="1.99339e-05" />
            <origin xyz="0.014906 0.00987606 0.0198976" rpy="0 -0 0" />
            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
        </inertial>
        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
    </link>
    <link name="servo_hx30_1">
        <inertial>
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

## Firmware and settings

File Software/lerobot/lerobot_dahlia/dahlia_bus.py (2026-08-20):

"""lerobot MotorsBus for the Dahlia arm's Hiwonder HX bus servos.

The arm is not wired the way a lerobot follower normally is. There is no serial port
on this host that reaches the servos:

    lerobot (this PC)
       |  HTTP, raw servo ticks
    spi_service brick        (UNO Q, Linux side)
       |  SPI, 100 Hz
    sketch.ino               (UNO Q, Zephyr MCU -- owns the servo loop at 200 Hz)
       |  UART, Hiwonder 0xFF protocol      |  PWM
    HX-HM bus servos (5 joints)             clamp servo (gripper)

So this is a proxy bus rather than a serial one. Two things force that shape:

  * The gripper is a plain PWM hobby servo on an MCU pin, not a node on the servo
    bus. A direct host-to-bus connection physically cannot reach it, so the sixth
    degree of freedom only exists through the firmware.
  * The MCU runs the closed servo loop, the mechanical joint limits and the command
    watchdog. Going around it would give those up.

Everything on the wire is in raw servo ticks, so lerobot's own calibration,
normalisation and teleoperation flows work exactly as they do on a serial bus.

Notes on the hardware, which differs from Feetech in two ways that matter:

  * Position is signed and centred on 0 (roughly -30719..30719), not unsigned
    0..4095. "Half turn homing" therefore targets 0, the servo's own centre.
  * Calibration is kept host-side. The servos' non-volatile position-offset register
    is deliberately never written -- offsets are applied here, in the read and write
    paths, which keeps calibration reproducible and avoids wearing the servo NVS.

The register map is otherwise identical to Feetech STS, because these servos speak
the same protocol.

Bring-up:

    python -m lerobot_dahlia.dahlia_bus http://dahlia.local:9000
"""

from __future__ import annotations

import http.client
import json
import logging
import socket
import time
from collections.abc import Sequence
from contextlib import contextmanager
from pprint import pformat
from urllib.parse import urlparse

from lerobot.motors.motors_bus import (
    Motor,
    MotorCalibration,
    MotorNormMode,
    MotorsBusBase,
    NameOrID,
    Value,
)
from lerobot.utils.decorators import check_if_already_connected, check_if_not_connected
from lerobot.utils.utils import enter_pressed, move_cursor_up

logger = logging.getLogger(__name__)


# --- the arm ----------------------------------------------------------------

# Order is the packet order the firmware uses, so index i here is joint i there.
JOINT_NAMES = ("base", "shoulder", "elbow", "wrist_pitch", "wrist_roll")
GRIPPER_NAME = "gripper"

# The clamp has no encoder, so its "present position" is the echo of what was last
# commanded. Modelled as a motor anyway, so a policy sees one uniform action vector.
GRIPPER_MODEL = "dahlia-clamp"

# 12-bit magnetic encoder. Only used for degree-mode normalisation and as the default
# calibration span; the real travel of each joint comes from the firmware.
HX_RESOLUTION = 4096
GRIPPER_RESOLUTION = 256

# Servo units, matching the clamps in HXServo and in the firmware.
MAX_VELOCITY = 3400
MAX_ACCELERATION = 254

MODEL_RESOLUTION_TABLE = {
    "hx-10hm": HX_RESOLUTION,
    "hx-30hm": HX_RESOLUTION,
    "hx-65hm": HX_RESOLUTION,
    GRIPPER_MODEL: GRIPPER_RESOLUTION,
}

# Kept for reference and for anyone who later drives these servos directly: the HX-HM
# control table is the Feetech STS table, so lerobot's FeetechMotorsBus addresses
# apply unchanged. The proxy addresses registers by name, not by address.
HX_CONTROL_TABLE = {
    "ID": (5, 1),
    "Baud_Rate": (6, 1),
    "Homing_Offset": (31, 2),
    "Operating_Mode": (33, 1),
    "Torque_Enable": (40, 1),
    "Acceleration": (41, 1),
    "Goal_Position": (42, 2),
    "Goal_Velocity": (46, 2),
    "Maximum_Torque": (48, 2),
    "Present_Position": (56, 2),
    "Present_Velocity": (58, 2),
    "Present_Load": (60, 2),
    "Present_Voltage": (62, 1),
    "Present_Temperature": (63, 1),
    "Moving": (66, 1),
    "Present_Current": (69, 2),
}

# Register name -> key in the service's motor-state response.
_READABLE = {
    "Present_Position": "raw_positions",
    "Present_Velocity": "raw_velocities",
    "Present_Load": "raw_loads",
    "Present_Voltage": "voltages",
    "Present_Temperature": "temperatures",
    "Torque_Enable": "torque",
}

# Registers only the bus servos can answer. The clamp is PWM with no sensing at all,
# and unlike velocity or load there is no honest stand-in value -- reporting 0 V or
# 0 C would be a lie a safety check could act on. So a read over "every motor" means
# every motor that can actually answer.
_JOINT_ONLY = {"Present_Voltage", "Present_Temperature"}

# Register name -> key in the service's command body.
_WRITABLE = {
    "Goal_Position": "positions",
    "Goal_Velocity": "velocities",
    "Acceleration": "acceleration",
    "Torque_Enable": "torque",
}


# Mirrors ControlMode in sketch/src/spi/spi_service.h. The service keeps one command
# struct with one mode field, and /targets and /motors each overwrite the other's, so
# the mode also says which client currently owns the arm.
MODE_HOLD, MODE_ANGLE, MODE_RAW = 0, 1, 2


# As built: the shoulder carries the whole arm and gets the high torque servo, the
# rest are HX-30HM. Resolution is 4096 across the family, so this only affects
# reporting and the control table lookup, not any of the maths.
JOINT_MODELS = {
    "base": "hx-30hm",
    "shoulder": "hx-65hm",
    "elbow": "hx-30hm",
    "wrist_pitch": "hx-30hm",
    "wrist_roll": "hx-30hm",
}


def dahlia_motors(
    joint_models: dict[str, str] | None = None,
    norm_mode: MotorNormMode = MotorNormMode.RANGE_M100_100,
) -> dict[str, Motor]:
    """The standard six-motor layout, ids matching joint_configs in the firmware."""
    joint_models = JOINT_MODELS if joint_models is None else joint_models

    motors = {
        name: Motor(id=index + 1, model=joint_models[name], norm_mode=norm_mode)
        for index, name in enumerate(JOINT_NAMES)
    }
    # The clamp is driven by PWM, so its id is nominal; it is never addressed on the bus.
    motors[GRIPPER_NAME] = Motor(id=6, model=GRIPPER_MODEL, norm_mode=MotorNormMode.RANGE_0_100)
    return motors


# --- transport --------------------------------------------------------------


class _Session:
    """Keep-alive JSON client for the brick service.

    A control loop makes two requests per tick from another machine, so the
    connection is held open across them. urllib would open a fresh TCP connection
    every time, which at 30 Hz is most of the latency budget spent on handshakes.
    """

    def __init__(self, base_url: str, timeout: float):
        parsed = urlparse(base_url if "//" in base_url else f"http://{base_url}")

        if parsed.scheme not in ("http", ""):
            raise ValueError(f"Only http:// is supported, got '{base_url}'")

        self.host = parsed.hostname or "localhost"
        self.port = parsed.port or 9000
        self.timeout = timeout
        self._conn: http.client.HTTPConnection | None = None

    def __repr__(self) -> str:
        return f"http://{self.host}:{self.port}"

    def connect(self) -> None:
        self.close()
        self._conn = http.client.HTTPConnection(self.host, self.port, timeout=self.timeout)
        self._conn.connect()

    def close(self) -> None:
        if self._conn is not None:
            self._conn.close()
            self._conn = None

    @property
    def is_connected(self) -> bool:
        return self._conn is not None

    def request(self, method: str, path: str, body: dict | None = None, num_retry: int = 0) -> dict:
        """One JSON round trip, reopening the connection if it has gone away.

        A keep-alive connection can be closed by the far end at any time, so the
        first attempt after an idle gap is expected to fail occasionally. That is a
        reconnect, not an error worth surfacing, hence the retry floor of one.
        """
        payload = json.dumps(body).encode("utf-8") if body is not None else None
        headers = {"Accept": "application/json"}

        if payload is not None:
            headers["Content-Type"] = "application/json"
            headers["Content-Length"] = str(len(payload))

        last_error: Exception | None = None

        for attempt in range(2 + num_retry):
            try:
                if self._conn is None:
                    self.connect()

                self._conn.request(method, path, body=payload, headers=headers)
                response = self._conn.getresponse()
                data = response.read()

                if response.status != 200:
                    raise ConnectionError(
                        f"{method} {path} returned {response.status} {response.reason}: "
                        f"{data.decode('utf-8', 'replace')[:200]}"
                    )

                return json.loads(data)

            except (http.client.HTTPException, OSError, socket.timeout, ValueError) as e:
                last_error = e
                self.close()
                logger.debug(f"{method} {path} failed ({attempt=}): {e!r}")

        raise ConnectionError(
            f"Could not reach the Dahlia SPI service at {self}. "
            f"Check the board is up and the brick is running. Last error: {last_error!r}"
        ) from last_error


# --- the bus ----------------------------------------------------------------


class HXServoMotorsBus(MotorsBusBase):
    """A lerobot MotorsBus backed by the Dahlia firmware's raw motor API.

    `port` is the service URL rather than a serial device, e.g.
    `"http://dahlia.local:9000"`, which keeps it usable as a plain `port` field in a
    lerobot RobotConfig.

    Example:
        ```python
        bus = HXServoMotorsBus("http://dahlia.local:9000", dahlia_motors())
        bus.connect()
        bus.enable_torque()
        print(bus.sync_read("Present_Position", normalize=False))
        bus.disconnect()
        ```
    """

    apply_drive_mode = True
    normalized_data = ["Goal_Position", "Present_Position"]
    model_resolution_table = MODEL_RESOLUTION_TABLE
    model_ctrl_table = {model: HX_CONTROL_TABLE for model in MODEL_RESOLUTION_TABLE}

    # The clamp's echo is not a measurement, so it is left out of anything that needs
    # a joint to actually move.
    default_velocity = MAX_VELOCITY
    default_acceleration = MAX_ACCELERATION

    def __init__(
        self,
        port: str,
        motors: dict[str, Motor] | None = None,
        calibration: dict[str, MotorCalibration] | None = None,
        timeout: float = 1.0,
    ):
        super().__init__(port, motors if motors is not None else dahlia_motors(), calibration)

        self._session = _Session(port, timeout)
        self._config: dict = {}

        # The service takes whole arrays, so a write that touches one motor still has
        # to state the others. These hold what was last commanded.
        self._goal_position: dict[str, int] = {}
        self._goal_velocity: dict[str, int] = dict.fromkeys(self.motors, self.default_velocity)
        self._goal_acceleration: dict[str, int] = dict.fromkeys(self.motors, self.default_acceleration)
        self._torque: dict[str, bool] = dict.fromkeys(self.motors, False)

        # Set from every state the service returns; None until the first one arrives.
        self._effective_mode: int | None = None

        self._validate_motors()

    def __len__(self) -> int:
        return len(self.motors)

    def __repr__(self) -> str:
        return (
            f"{self.__class__.__name__}(\n"
            f"    Service: '{self._session}',\n"
            f"    Motors: \n{pformat(self.motors, indent=8, sort_dicts=False)},\n"
            ")',\n"
        )

    # --- motor bookkeeping -------------------------------------------------

    def _validate_motors(self) -> None:
        missing = [name for name in JOINT_NAMES if name not in self.motors]
        if missing:
            raise ValueError(
                f"The firmware addresses joints by packet position, so all of {JOINT_NAMES} "
                f"must be present. Missing: {missing}"
            )

        ids = [m.id for m in self.motors.values()]
        if len(ids) != len(set(ids)):
            raise ValueError(f"Some motors have the same id!\n{self}")

        for name, motor in self.motors.items():
            if motor.model not in self.model_resolution_table:
                raise KeyError(f"Unknown model '{motor.model}' for motor '{name}'.")

    def _get_motors_list(self, motors: NameOrID | Sequence[NameOrID] | None) -> list[str]:
        if motors is None:
            return list(self.motors)
        if isinstance(motors, str):
            return [motors]
        if isinstance(motors, int):
            return [self._id_to_name(motors)]
        if isinstance(motors, Sequence):
            return [m if isinstance(m, str) else self._id_to_name(m) for m in motors]
        raise TypeError(motors)

    def _id_to_name(self, motor_id: int) -> str:
        for name, motor in self.motors.items():
            if motor.id == motor_id:
                return name
        raise KeyError(f"No motor with id {motor_id}.")

    def _joint_index(self, motor: str) -> int | None:
        """Packet index of a motor, or None for the gripper, which is not a joint."""
        return JOINT_NAMES.index(motor) if motor in JOINT_NAMES else None

    def _has_feedback(self, motor: str) -> bool:
        """Whether a motor actually measures its position."""
        return motor in JOINT_NAMES

    # --- connection --------------------------------------------------------

    @property
    def is_connected(self) -> bool:
        return self._session.is_connected

    @check_if_already_connected
    def connect(self, handshake: bool = True) -> None:
        """Open the session to the service and adopt the arm's current pose.

        Args:
            handshake: Verify the service is talking to a live MCU before returning.

        Raises:
            ConnectionError: The service is unreachable, or is up but not exchanging
                frames with the MCU.
        """
        self._session.connect()

        try:
            self._config = self._session.request("GET", "/config")

            if handshake:
                self._handshake()

            # Seed the goals from where the arm actually is, so the first sync_write
            # cannot fling a joint across its range for the motors it does not name.
            state = self._state()
            for motor in self.motors:
                self._goal_position[motor] = self._raw_from_state(state, motor, "Present_Position")
                self._torque[motor] = bool(self._raw_from_state(state, motor, "Torque_Enable"))

        except Exception:
            self._session.close()
            raise

        logger.debug(f"{self.__class__.__name__} connected to {self._session}.")

    def _handshake(self) -> None:
        service_joints = self._config.get("joints")

        if service_joints is not None and list(service_joints) != list(JOINT_NAMES):
            raise ConnectionError(
                f"The service reports joints {service_joints}, this bus expects {list(JOINT_NAMES)}. "
                "One side is out of date."
            )

        state = self._state()

        if state.get("comm_errors") and any(state["comm_errors"]):
            offline = [n for n, bad in zip(JOINT_NAMES, state["comm_errors"]) if bad]
            raise ConnectionError(
                f"The MCU is not getting telemetry from: {offline}. Check servo power, "
                "the bus wiring and that each servo has its expected id."
            )

    @check_if_not_connected
    def disconnect(self, disable_torque: bool = True) -> None:
        """Close the session, optionally letting the arm go limp first.

        Args:
            disable_torque: If True, torque is disabled before disconnecting. Note
                that this drops the arm under its own weight -- pass False to leave
                it holding its pose.
        """
        if disable_torque:
            try:
                self.disable_torque(num_retry=2)
            except ConnectionError as e:
                logger.warning(f"Could not disable torque on disconnect: {e}")

        self._session.close()
        logger.debug(f"{self.__class__.__name__} disconnected.")

    # --- service access ----------------------------------------------------

    def _state(self, num_retry: int = 0) -> dict:
        """Newest motor state, or raise if the service cannot supply one."""
        payload = self._session.request("GET", "/motors", num_retry=num_retry)
        return self._check_state(payload)

    def _command(self, body: dict, num_retry: int = 0) -> dict:
        """Push a command and take the state that comes back in the same response."""
        payload = self._session.request("POST", "/motors", body=body, num_retry=num_retry)
        return self._check_state(payload)

    def _check_state(self, payload: dict) -> dict:
        if not payload.get("ok"):
            raise ConnectionError(
                f"The SPI service has no valid frame from the MCU: {payload.get('error')}"
            )

        # The mode the MCU is acting on. It only reads MODE_HOLD if the service itself
        # stops clocking frames, not if a client stops posting, so this tracks which
        # command space is selected rather than whether anyone is still driving it.
        self._effective_mode = payload.get("mode")

        if payload.get("stale"):
            # The MCU has fallen back to holding its pose because commands stopped
            # arriving in time. Reads are still valid, so warn rather than raise.
            logger.warning(
                "The MCU reports a stale command: the host is not keeping up with the "
                "watchdog. The arm is holding its pose."
            )

        if any(payload.get("comm_errors", [])):
            offline = [n for n, bad in zip(JOINT_NAMES, payload["comm_errors"]) if bad]
            logger.warning(f"The MCU missed telemetry from: {offline}")

        return payload

    def commanding_in_radians(self) -> bool:
        """Whether the command space is currently set to radians, i.e. /targets last wrote it.

        Useful as a conflict check, not as a liveness check. The service resends the
        command struct at 100 Hz whether or not anything is updating it, so the MCU
        stays "fresh" as long as the brick runs and the mode keeps whatever was last
        posted. A single POST to /targets therefore leaves this true indefinitely,
        even if the loop that sent it has since stopped. It says the SEC path was the
        last writer, never that it is still running.

        Answered from the last state the service returned, which every read and every
        write already carries, so asking costs no extra request.
        """
        return self._effective_mode == MODE_ANGLE

    def _raw_from_state(self, state: dict, motor: str, data_name: str) -> int:
        """Pull one motor's raw value for a register out of a state response."""
        index = self._joint_index(motor)

        if index is None:
            # The clamp only exists as the gripper byte, which is the commanded
            # closure echoed back rather than anything measured.
            if data_name in ("Present_Position", "Goal_Position"):
                return int(state["gripper"])
            if data_name == "Torque_Enable":
                return 1   # PWM is always driven; there is no torque to switch
            if data_name in ("Present_Velocity", "Present_Load"):
                return 0
            raise KeyError(f"'{data_name}' is not available for '{motor}'.")

        key = _READABLE.get(data_name)

        if key is None:
            raise KeyError(
                f"'{data_name}' is not readable through the firmware proxy. "
                f"Available: {sorted(_READABLE)}"
            )

        value = state[key][index]
        return int(value) if not isinstance(value, bool) else int(value)

    # --- calibration -------------------------------------------------------

    @property
    def is_calibrated(self) -> bool:
        return set(self.calibration) == set(self.motors)

    def read_calibration(self) -> dict[str, MotorCalibration]:
        """The calibration in effect.

        Unlike a serial bus this does not query the servos: offsets and ranges are
        applied host-side and never written to servo NVS, so this bus is the only
        place they live.
        """
        return dict(self.calibration)

    def write_calibration(
        self, calibration_dict: dict[str, MotorCalibration], cache: bool = True
    ) -> None:
        unknown = set(calibration_dict) - set(self.motors)
        if unknown:
            raise ValueError(f"Calibration for motors that are not on this bus: {sorted(unknown)}")

        if cache:
            self.calibration = calibration_dict

    def reset_calibration(self, motors: NameOrID | Sequence[NameOrID] | None = None) -> None:
        """Restore the full mechanical range and a zero offset for the given motors."""
        for motor in self._get_motors_list(motors):
            self.calibration[motor] = MotorCalibration(
                id=self.motors[motor].id,
                drive_mode=0,
                homing_offset=0,
                range_min=self._default_range(motor)[0],
                range_max=self._default_range(motor)[1],
            )

    def _default_range(self, motor: str) -> tuple[int, int]:
        """The joint's travel as the firmware enforces it, in ticks."""
        index = self._joint_index(motor)

        if index is None:
            return 0, GRIPPER_RESOLUTION - 1

        limits = self._config.get("tick_limits")

        if limits is not None and index < len(limits):
            return int(limits[index][0]), int(limits[index][1])
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

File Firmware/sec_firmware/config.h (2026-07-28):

#ifndef CONFIG_H
#define CONFIG_H

#include <Arduino.h>

// Joystick, KY-023
constexpr int JOY_X_PIN = 4;
constexpr int JOY_Y_PIN = 5;
constexpr int JOY_SW_PIN = 6;

// Rotary Encoder, KY-040
constexpr int ENC_A_PIN = 9;
constexpr int ENC_B_PIN = 10;
constexpr int ENC_SW_PIN = 11;

// IMU, MPU6050 (I2C)
constexpr int IMU_SDA_PIN = 13;
constexpr int IMU_SCL_PIN = 14;

// Display, MAX7219 (SPI)
constexpr int DSPLY_DIN_PIN = 40;
constexpr int DSPLY_CS_PIN = 41;
constexpr int DSPLY_CLK_PIN = 42;

#endif /* CONFIG_H */

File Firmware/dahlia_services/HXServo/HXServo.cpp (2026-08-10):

/**
 * @file    HXServo.cpp
 * @brief   Implementation of the HXServo Arduino driver.
 *
 * Ported from Hiwonder's ESP32-only "HX_30HM" reference implementation.
 * Protocol logic is unchanged; the port removes ESP32-specific serial calls,
 * moves port start-up into begin(), and fixes the goal-speed field in the
 * "_ex" position helpers. See README.md > "Changes from the original".
 */
#include "HXServo.h"

/* Convert a signed host value to the servo's sign-magnitude wire form: the
 * magnitude in the low bits and the sign in @c bit. */
#define MASK_HOST(x, bit)  ((x) < 0 ? (-(x)) | ((1U) << (bit)) : (x))

/* Inverse of MASK_HOST: recover a signed value from sign-magnitude form. */
#define MASK_SERVO(x, bit) (((x) & ((1U) << (bit))) != 0 ? -((x) & ~((1U) << (bit))) : (x))

/* Clamp x to [min, max]. */
#define LIMIT(x, min, max) (((x) < (min)) ? (min) : ((x) > (max)) ? (max) : (x))

/* -------------------------------------------------------------------------
 * Construction / start-up
 * ---------------------------------------------------------------------- */
HXServo::HXServo(HardwareSerial &serial, uint32_t baud)
{
    uart       = &serial;
    baudrate   = baud;
    rx_skip    = 1;
    rx_timeout = 20;   /* ms */
    endianness = 0;    /* little-endian on the wire */
    rx_status  = PACKET_HEADER_1;
}

void HXServo::begin()
{
    uart->begin(baudrate, SERIAL_8N1);
}

void HXServo::begin(uint32_t baud)
{
    baudrate = baud;
    begin();
}

/* -------------------------------------------------------------------------
 * Byte / word helpers
 * ---------------------------------------------------------------------- */
void HXServo::word2bytes(uint16_t word, uint8_t *bytes_l, uint8_t *bytes_h)
{
    if (endianness) {
        *bytes_l = (word >> 8);
        *bytes_h = (word & 0xff);
    } else {
        *bytes_h = (word >> 8);
        *bytes_l = (word & 0xff);
    }
}

uint16_t HXServo::bytes2word(uint8_t *bytes_l, uint8_t *bytes_h)
{
    uint16_t word;

    if (endianness) {
        word = *bytes_l;
        word <<= 8;
        word |= *bytes_h;
    } else {
        word = *bytes_h;
        word <<= 8;
        word |= *bytes_l;
    }
    return word;
}

/* Checksum: ~(sum of every byte after the two header bytes). */
uint8_t HXServo::data_check(const uint8_t buf[], uint8_t len)
{
    uint16_t temp = 0;
    for (int i = 2; i < len; ++i) {
        temp += buf[i];
    }
    return (uint8_t)(~temp);
}

/* -------------------------------------------------------------------------
 * Frame parsing (receive)
 * ---------------------------------------------------------------------- */
uint8_t HXServo::unpack()
{
    uint8_t error;
    uint8_t check_value;

    rx_status = PACKET_HEADER_1;

    while (uart->available()) {
        switch (rx_status) {
            case PACKET_HEADER_1:
                rx_packet.header_1 = uart->read();
                rx_status = rx_packet.header_1 == FRAME_HEADER_1 ? PACKET_HEADER_2 : PACKET_HEADER_1;
                break;

            case PACKET_HEADER_2:
                rx_packet.header_2 = uart->read();
                rx_status = rx_packet.header_2 == FRAME_HEADER_2 ? PACKET_ID : PACKET_HEADER_1;
                break;

            case PACKET_ID:
                rx_packet.elements.id = uart->read();
                rx_status = rx_packet.elements.id <= BROADCAST_ID ? PACKET_DATA_LENGTH : PACKET_HEADER_1;
                break;

            case PACKET_DATA_LENGTH:
                rx_packet.elements.length = uart->read();
                rx_status = rx_packet.elements.length <= HX_MAX_FRAME_SIZE + 1 ? PACKET_CMD : PACKET_HEADER_1;
                break;

            case PACKET_CMD:
                rx_packet.elements.cmd = uart->read();
                rx_status = rx_packet.elements.cmd <= CMD_SYNC_READ ? PACKET_PARAMETERS : PACKET_HEADER_1;
                break;

            case PACKET_PARAMETERS:
                for (uint8_t i = 0; i < rx_packet.elements.length - 2; i++) {
                    rx_packet.elements.args[i] = uart->read();
                }
                rx_status = PACKET_CHECKSUM;
                break;

            case PACKET_CHECKSUM:
                rx_packet.elements.args[rx_packet.elements.length - 2] = uart->read();
                check_value = data_check((const uint8_t *)&rx_packet, rx_packet.elements.length + 3);
                rx_status = rx_packet.elements.args[rx_packet.elements.length - 2] == check_value
                                ? PACKET_FINISH
                                : PACKET_HEADER_1;
                break;

            default:
                break;
        }

        if (rx_status == PACKET_FINISH) {
            break;
        }
    }

    error = rx_status == PACKET_FINISH ? 0 : 1;
    return error;
}

/* -------------------------------------------------------------------------
 * Frame building (transmit)
 * ---------------------------------------------------------------------- */
uint8_t HXServo::tx_frame_write(uint8_t id, uint8_t cmd, const uint8_t *data, uint8_t data_len)
{
    uint8_t frame_len = 6 + data_len;   /* header1 + header2 + id + length + cmd + checksum */
    uint8_t packet[frame_len];

    packet[0] = FRAME_HEADER_1;
    packet[1] = FRAME_HEADER_2;
    packet[2] = id;
    packet[3] = 2 + data_len;           /* length = cmd + params + checksum */
    packet[4] = cmd;

    for (uint8_t i = 0; i < data_len; i++) {
        packet[5 + i] = data[i];
    }

    packet[frame_len - 1] = data_check((const uint8_t *)packet, frame_len - 1);

#if HX_DEBUG
    HX_DEBUG_STREAM.print("TX: ");
    for (uint8_t i = 0; i < frame_len; i++) {
        HX_DEBUG_STREAM.print(packet[i], HEX);
        HX_DEBUG_STREAM.print(' ');
    }
    HX_DEBUG_STREAM.println();
#endif

    return uart->write(packet, frame_len);
}

/* -------------------------------------------------------------------------
 * Reply handling
 * ---------------------------------------------------------------------- */
ServoStatus_t HXServo::ack()
{
    ServoStatus_t status;
    uint8_t size;
    uint32_t tickstart;

    status.id = 0xFF;
    status.error_byte = 0;

    if (!rx_skip) {
        tickstart = millis();
        while (1) {
            size = uart->available();
            if (size >= rx_frame_length) {
                break;
            }
            if (millis() - tickstart > rx_timeout) {
                status.error_bits.bit_rx = 1;
                return status;
            }
        }

        if (unpack()) {
            status.error_bits.bit_rx = 1;
        } else {
            status.id = rx_packet.elements.id;
            status.error_byte = rx_packet.elements.cmd;
        }
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

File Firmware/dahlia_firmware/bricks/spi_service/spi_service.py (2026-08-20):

"""SPI state exchange service between the Linux MPU and Arduino MCU.

Every SPI transaction exchanges the newest command (TX) for the newest feedback (RX).
The HTTP server and SPI loop are independent, thus allowing any controller to POST
to targets to send commands. SPI thread syncs with the MCU at nominal 100 Hz.

Commands are states, not events. Each POST updates only fields it carries and
all other data fields are left alone by the SPI loop and resent.

Two command spaces share the frame:

    /targets   radians, joint limits enforced by the MCU based on the URDF. Used by the
               BLE teleoperation path in python/main.py.
    /motors    raw servo ticks. Used by anything that owns its own calibration, such
               as the lerobot MotorsBus in Software/lerobot/lerobot_hxservo.py.

Only one of them is in effect at a time, selected by the mode field.
"""

import json
import os
import struct
import threading
import time
from dataclasses import dataclass, field
from http.server import BaseHTTPRequestHandler, ThreadingHTTPServer

import spidev

HOST = os.environ.get("SPI_SERVICE_HOST", "0.0.0.0")
PORT = int(os.environ.get("SPI_SERVICE_PORT", "9000"))

NUM_JOINTS = 5
COMMAND_MAGIC = 0xA5
FEEDBACK_MAGIC = 0x5A

# Mirrors ControlMode in `spi_service.h`
MODE_HOLD, MODE_ANGLE, MODE_RAW = 0, 1, 2

# Mirrors FeedbackPacket in `spi_service.h`
TORQUE_APPLY = 0x80

STATUS_TORQUE = 0x01
STATUS_MOVING = 0x02
STATUS_STALE = 0x04

_N = NUM_JOINTS
COMMAND_FORMAT = "<BBBB" + f"{_N}f{_N}f{_N}h{_N}h{_N}B" + "B"
FEEDBACK_FORMAT = "<BBBB" + f"{_N}f{_N}f{_N}h{_N}h{_N}h{_N}B{_N}B" + "BBBH"

COMMAND_SIZE = struct.calcsize(COMMAND_FORMAT)
FEEDBACK_SIZE = struct.calcsize(FEEDBACK_FORMAT)

# MCU transceives data in fixed buffer of the larger size of the data structs.
FRAME_SIZE = max(COMMAND_SIZE, FEEDBACK_SIZE)

SPI_PERIOD = 0.01   # 100 Hz
SPI_SPEED_HZ = 1000000

# Joint limits from `servo_interface.h`, ordered numerically rather than by travel direction.
JOINT_NAMES = ("base", "shoulder", "elbow", "wrist_pitch", "wrist_roll")
JOINT_TICK_LIMITS = ((-1250, 1250), (-200, 2200), (0, 2250), (-1024, 1024), (800, 2700))
JOINT_ANGLE_LIMITS = ((-1.917, 1.917), (-3.375, 0.307), (0.0, 3.451), (-1.534, 1.534), (-1.457, 1.457))

TICKS_PER_TURN = 4096

GRIPPER_MIN = 0
GRIPPER_MAX = 255

MAX_BODY_BYTES = 64 * 1024
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

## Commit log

2026-07-28 Arm and SEC firmware
2026-07-30 updates to servo control, pwm, and HXServo
2026-07-30 revert changes to HXServo, fix low level control issues
    [sketch.ino]
2026-07-30 fix servo jittering using hardware pwm
2026-07-31 spi service
2026-08-01 working spi brick and bluetooth control
2026-08-01 decouple servo velocity from commanded rate
2026-08-01 improved servo run to target
2026-08-02 control updates to match new urdf spec
2026-08-03 update servo limits to match fixed urdf
    [servo_interface.h]
2026-08-09 microtag blocks and basic homography detection
    [MicroTag Block.stl, MicroTag Frame.stl, MicroTag Piece.stl]
2026-08-20 control fix and lerobot integration
    [dahlia_bus.py, servo_interface.h]
2026-09-14 hardware and additional documentation
    [arm_lower_arm.step, arm_lower_arm.stl, arm_upper_arm.step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]
